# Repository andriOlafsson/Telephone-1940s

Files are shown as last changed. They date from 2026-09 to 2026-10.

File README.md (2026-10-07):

# Telephone-1940s

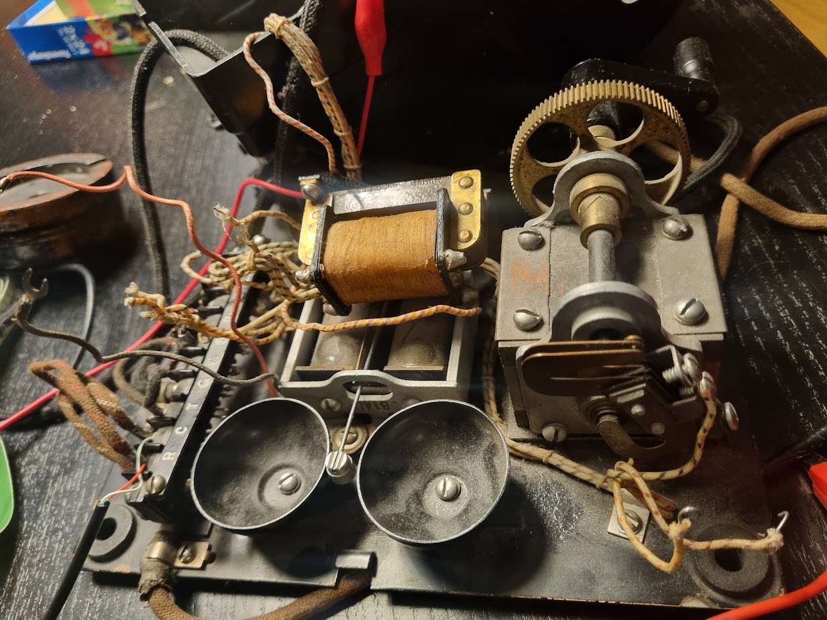
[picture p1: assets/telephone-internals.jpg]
Inside the Western Electric telephone, showing its original bell mechanism

*Photo from the [full project story](https://munir.is/en/literature/grandfathers-telephone).*

This is a completed family-history project built around my grandfather's Western Electric telephone, first put into use around 1940 at Dvergasteinn in Reyðarfjörður. The phone's number was 52. Today, turning its original crank rings the mechanical bells; lifting the receiver plays a recording in which my aunt Valgerður tells the phone's story.

Read the full story: [Grandfather's telephone — Andri - Datadude](https://munir.is/en/literature/grandfathers-telephone).

This repository documents one working installation and shares its code and supporting files. It is a hardware-specific reference build, not a tested, turn-key kit.

## How it works

- Turning the magneto crank while the receiver is on its hook triggers the ringer.
- The Raspberry Pi reads the hook and crank switches and controls a Silvertel AG1171 ringing module, which drives the phone's original bell.
- Lifting the receiver stops ringing and plays the recording after a 500 ms pause. Replacing the receiver stops playback.
- The Python program uses GPIO event detection with a 200 ms debounce to handle the phone's old mechanical contacts.

## Hardware and safety

The original installation uses:

- A Western Electric telephone with a mechanical bell, receiver, and magneto crank.
- A 2011 Raspberry Pi Model B, Revision 1.
- A Silvertel AG1171 ringing module.
- A separate audio recording (`valgerdur.wav` in the original setup); the recording is not included in this repository.

**Electrical caution:** the AG1171 produces approximately 90 V AC for the bell. Treat its ringing output as hazardous, disconnect power before wiring, and follow the [AG1171 datasheet](Ag1171-datasheet-Low-cost-ringing-SLIC-with-single-supply.pdf). Do not power the ringer from the Pi's 5 V rail: the current draw caused voltage drops and SD-card corruption during this build.

This project involves old, hardware-specific wiring and a high-voltage ringing circuit. Verify your exact Raspberry Pi board revision and telephone wiring before connecting anything.

## GPIO assignments

The script uses **BCM GPIO numbering**:

| Signal | BCM GPIO | Direction | Pull / active state |
| --- | ---: | --- | --- |
| Receiver hook switch | 17 | Input | Internal pull-down; HIGH when lifted |
| Magneto crank switch | 26 | Input | Internal pull-up; LOW when cranked |
| AG1171 ring mode (RM) | 27 | Output | HIGH while ringing |
| AG1171 forward/reverse (FR) | 22 | Output | Alternates to produce the ringing signal |

These are the assignments in [`2026-03-08-ringer-hook.py`](2026-03-08-ringer-hook.py), not physical header pin numbers. Check the pinout for your exact Pi revision before wiring; the original Model B Revision 1 differs from later boards.

## Run the program

1. Prepare a Raspberry Pi with a compatible Raspberry Pi OS, Python 3, `RPi.GPIO`, and `pygame`. The original project used an early Raspberry Pi Model B; package availability and GPIO support vary by OS version.
2. Connect the hook switch, magneto switch, and AG1171 control inputs according to the table above and the module datasheet. Keep the ringer's power supply separate from the Pi.
3. Provide the audio recording yourself. The script defaults to `/home/andri/tele/valgerdur.wav`; either place your recording at that path or edit `SOUND_FILE` near the top of the script.
4. From the repository directory, run:

   ```bash
   python3 2026-03-08-ringer-hook.py
   ```

5. With the receiver on its hook, turn the magneto crank and confirm that the bell rings. Lift the receiver to stop ringing and hear the recording; replace it to stop playback. Stop the program with `Ctrl+C`.

The repository does not include a systemd service or a known-good OS image. The script must be run in an environment with working GPIO access and audio output. For later Raspberry Pi deployment notes—including audio setup—see [`new_raspberry_model.md`](new_raspberry_model.md); those notes are not a validated setup recipe for the original Revision 1 board.

## Repository files

- [`2026-03-08-ringer-hook.py`](2026-03-08-ringer-hook.py) — GPIO monitoring, ringer control, and audio playback.
- [`new_raspberry_model.md`](new_raspberry_model.md) — notes from a later Raspberry Pi deployment.
- [`Ag1171-datasheet-Low-cost-ringing-SLIC-with-single-supply.pdf`](Ag1171-datasheet-Low-cost-ringing-SLIC-with-single-supply.pdf) — AG1171 datasheet.
- [`batterybox.3mf`](batterybox.3mf) and [`battery_label.jpg`](battery_label.jpg) — supporting enclosure and label assets.

## Development history

The first prototype used an Arduino and an MP3 module. I scrapped that code and moved the project to a Raspberry Pi so I could use Python for the GPIO and audio playback. The original build used a 2011 Raspberry Pi Model B, Revision 1; I later adapted the program for a Raspberry Pi 4.

The current script uses BCM GPIO assignments 17 (hook switch), 26 (magneto switch), 27 (AG1171 RM), and 22 (AG1171 FR). These are BCM GPIO numbers, not physical header-pin numbers. I still need to verify and document the Pi 4's physical wiring; see [issue #2](https://github.com/andriOlafsson/Telephone-1940s/issues/2).

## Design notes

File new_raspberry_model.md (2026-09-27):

sudo apt update && sudo apt install -y python3-rpi-lgpio python3-pygame alsa-utils git
And it even hopped onto your local network (`192.168.1.83`).

### 1. Update and Install System Packages

```bash
sudo apt update && sudo apt install -y python3-rpi-lgpio python3-pygame alsa-utils git

```

*(Using `python3-rpi-lgpio` ensures your existing `import RPi.GPIO as GPIO` code runs properly on modern Raspberry Pi OS without modifications).*

---

### 2. Verify Audio Output (3.5mm Jack)

Check the ALSA sound cards to make sure the headphone jack driver is active:

```bash
aplay -l

```

Test a built-in sound through the 3.5mm jack (plug in headphones or the telephone receiver leads):

```bash
speaker-test -t sine -f 440 -c 2 -s 1

```

*(Press `Ctrl + C` to stop it).*

---

### 3. Create the Directory and Transfer Your Files

Create the directory expected by your script:

```bash
mkdir -p /home/andri/tele

```

```powershell
scp path\to\valgerdur.wav andri@192.168.1.83:/home/andri/tele/
scp path\to\telephone.py andri@192.168.1.83:/home/andri/tele/

```

Once the files are copied over, test-run the script on the Pi:

```bash
python3 /home/andri/tele/telephone.py

```

---
needed to create "nano ~/.asoundrc" file in home directory to make the default audio device as the jack connector. Otherwise the default was alawys the hdmi even though nothing was plugged in. Stupid :)
content of asoundrc : 
pcm.!default {
    type asym
    playback.pcm {
        type plug
        slave.pcm "hw:Headphones,0"
    }
    capture.pcm {
        type plug
        slave.pcm "hw:Headphones,0"
    }
}

ctl.!default {
    type hw
    card Headphones
}
---
need to change the default volume setting (it is default at 40% so need to write alsamixer in the terminal to change the volume to 100%

Also noticing weird behaviour from the jack connector, it's noisy/screeching when nothing is playing, it was the same on the 2011 model of the raspberry pi. Squeeky noise coming and stopped for a moment when changing volume. Soe electrical inference

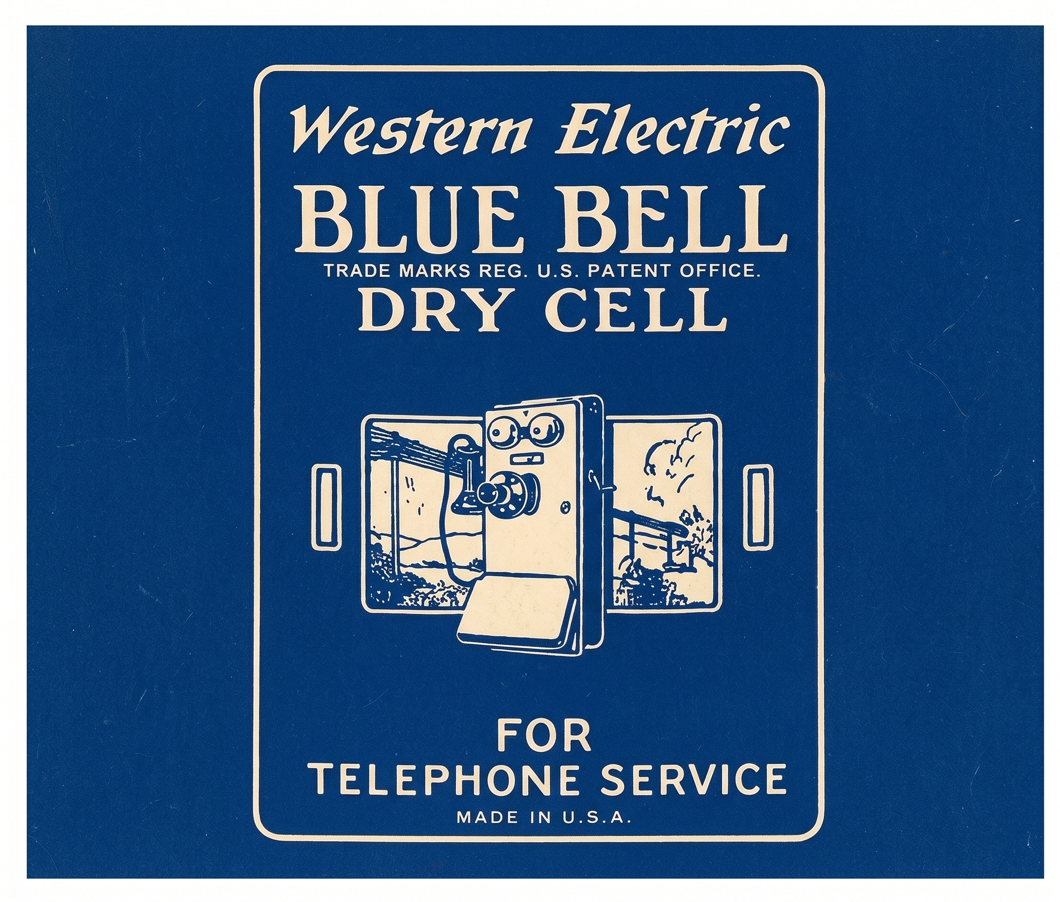
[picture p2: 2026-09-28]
battery_label.jpg

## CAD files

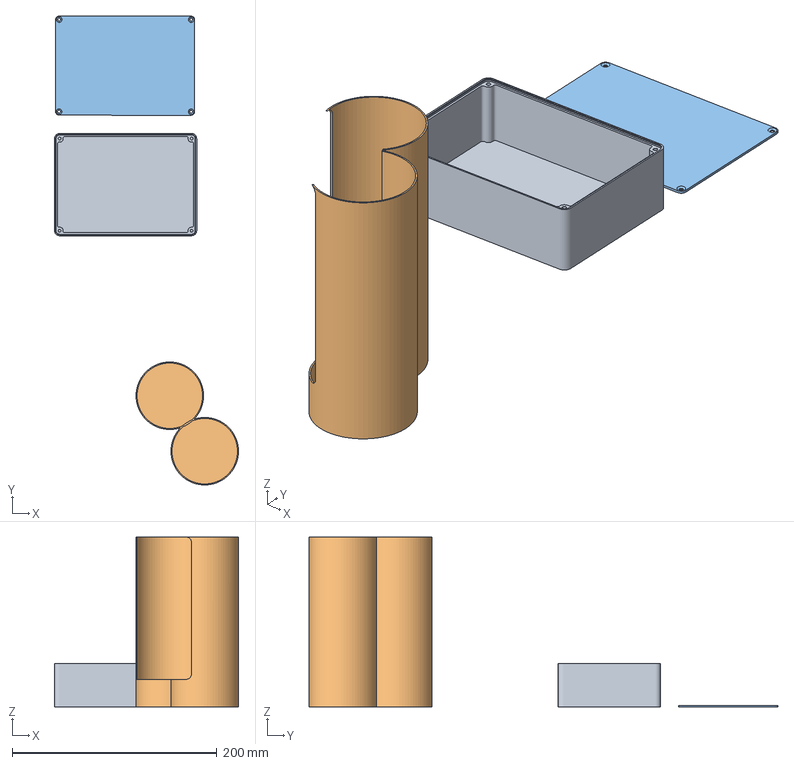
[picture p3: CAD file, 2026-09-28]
batterybox.3mf
179.8 x 458.2 x 166.0 mm
batterybox.stl_1
battery.stl_Boolean_Boolean_6
batterybox.stl_2

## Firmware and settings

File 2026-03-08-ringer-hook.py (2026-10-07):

import RPi.GPIO as GPIO
import time
import pygame.mixer
import os
import threading

# === CONFIGURATION ===
# Hook Switch: HIGH when handset is lifted (off-hook)
HOOK_SWITCH_PIN = 17

# Magneto Crank Switch: Connected to the crank mechanism
# Traditionally wired Normally Closed; goes LOW when cranked 1-5 degrees
MAGNETO_SWITCH_PIN = 26

# AG1171 Control Pins
RM_PIN = 27  # Ring Mode
FR_PIN = 22  # Forward/Reverse (Toggled for AC signal)

# Audio Settings
SOUND_FILE = "/home/andri/tele/valgerdur.wav"
SOUND_DELAY = 0.5  # Time for user to put phone to ear

# === GLOBAL VARIABLES ===
ringing_thread = None
stop_ringing_event = threading.Event()

# === INITIALIZATION ===
def setup():
    """Initializes GPIO and Audio Mixer."""
    GPIO.setmode(GPIO.BCM)
    
    # Hook switch uses a pull-down (HIGH when lifted)
    GPIO.setup(HOOK_SWITCH_PIN, GPIO.IN, pull_up_down=GPIO.PUD_DOWN)

    # Magneto switch uses a pull-up (LOW when cranked)
    GPIO.setup(MAGNETO_SWITCH_PIN, GPIO.IN, pull_up_down=GPIO.PUD_UP)

    # AG1171 outputs
    GPIO.setup(RM_PIN, GPIO.OUT, initial=GPIO.LOW)
    GPIO.setup(FR_PIN, GPIO.OUT, initial=GPIO.LOW)

    pygame.mixer.init()

# === RINGING LOGIC ===
def ring_loop():
    """Generates the 20Hz signal for mechanical bells via AG1171."""
    while not stop_ringing_event.is_set():
        # Ring ON phase
        GPIO.output(RM_PIN, GPIO.HIGH)
        # Toggle FR pin at ~20Hz (0.025s per state)
        for _ in range(10): 
            if stop_ringing_event.is_set():
                break
            GPIO.output(FR_PIN, GPIO.HIGH)
            time.sleep(0.025)
            GPIO.output(FR_PIN, GPIO.LOW)
            time.sleep(0.025)
        
        # Ring Cadence: 1s Ring, 3s Silence
        if stop_ringing_event.wait(1):
            break
            
        GPIO.output(RM_PIN, GPIO.LOW)
        if stop_ringing_event.wait(3):
            break

def start_ringing():
    global ringing_thread
    if ringing_thread is None or not ringing_thread.is_alive():
        stop_ringing_event.clear()
        ringing_thread = threading.Thread(target=ring_loop)
        ringing_thread.daemon = True
        ringing_thread.start()

def stop_ringing():
    stop_ringing_event.set()
    GPIO.output(RM_PIN, GPIO.LOW)

# === CALLBACK FUNCTIONS ===
def hook_switch_callback(channel):
    """Handles handset lifting/replacing."""
    if GPIO.input(HOOK_SWITCH_PIN) == GPIO.HIGH:
        # Handset is OFF-HOOK
        stop_ringing()
        
        # Short delay for user comfort before story starts
        time.sleep(SOUND_DELAY)
        
        if not pygame.mixer.get_busy():
            if os.path.exists(SOUND_FILE):
                pygame.mixer.Sound(SOUND_FILE).play()
            else:
                print(f"File {SOUND_FILE} not found.")
    else:
        # Handset is ON-HOOK
        pygame.mixer.stop()

def magneto_callback(channel):
    """Handles the magneto crank activation."""
    # Only allow ringing if the handset is on the hook
    if GPIO.input(HOOK_SWITCH_PIN) == GPIO.LOW:
        # If switch is engaged (LOW), start ringer; if released (HIGH), stop
        if GPIO.input(MAGNETO_SWITCH_PIN) == GPIO.LOW:
            start_ringing()
        else:
            stop_ringing()

# === MAIN LOOP ===
def main():
    print("REady - pick up the hook.")
    
    # Event detection with 200ms debounce to handle old mechanical contacts
    GPIO.add_event_detect(HOOK_SWITCH_PIN, GPIO.BOTH, callback=hook_switch_callback, bouncetime=200)
    GPIO.add_event_detect(MAGNETO_SWITCH_PIN, GPIO.BOTH, callback=magneto_callback, bouncetime=200)
    
    try:
        while True:
            time.sleep(1)
    except KeyboardInterrupt:
        print("\nShutting down.")
    finally:
        GPIO.cleanup()

if __name__ == "__main__":
    setup()
    main()

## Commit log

2026-03-08 Trying to get magneto to work
2026-09-27 changing the old raspberry out for a newer one - some todo's
2026-09-27 Document audio configuration for Raspberry Pi
    Added instructions for configuring audio settings on Raspberry Pi.
2026-09-27 Document volume and jack connector issues
    Added notes about default volume setting and jack connector issues.
2026-09-28 3d files for no.6 battery i created with a connector box
    [batterybox.3mf]
2026-09-28 battery label for 3d print
2026-10-07 Document Arduino and Raspberry Pi development history
